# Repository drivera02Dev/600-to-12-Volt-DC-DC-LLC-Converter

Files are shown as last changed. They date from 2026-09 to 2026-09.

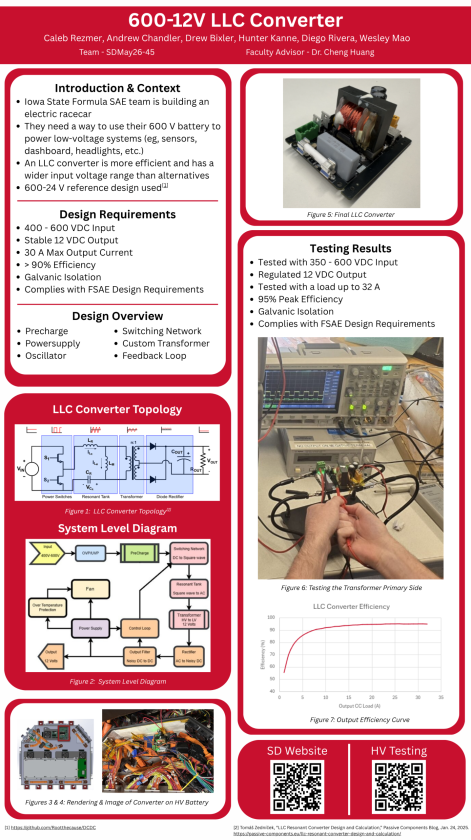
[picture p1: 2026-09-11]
600-12V LLC Converter.png

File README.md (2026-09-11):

# 600V-to-12V-DC-DC-Converter-Senior-Design-Project
## Team
- Caleb Rezmer 
- Drew Bixler 
- Hunter Kanne 
- Diego Rivera 
- Andrew Chandler 
- Wesley Mao

## Overview
This project was proposed by Caleb Rezmer for the FSAE club at Iowa State. This converter will go inside the electric formula car and it will use the 600 Volt battery from the car and step it down to 12 Volts at 30 Amps. It is stepped down to 12 Volts for the internals of the car such as lights, digital displays, fans, and anything else the team would want to add to the car that requires low voltage.

## Role
My role in the project was to make sure the power supply had the proper components it needs to function properly. I had to build and edit the schematic from the reference design we had. I had to verify that at the proper test points it was able to take that high voltage and keep the voltage at a steady 12 volts.

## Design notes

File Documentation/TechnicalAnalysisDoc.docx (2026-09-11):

# EE/CprE/SE 491 Technical Analysis Document Group number: sdmay26-45 Project title: 600-12 Volt Converter Client &/Advisor: Formula SAE

# Precharge/Discharge Circuit (Hunter):

The primary function of the Precharge & Discharge circuit is to charge the capacitor prior to supplying 600VDC current to the DC link capacitor and discharging the 600VDC of the DC link capacitor once the circuit is turned off, respectively. The Precharge circuit uses a constant current to reduce the amount of power going through the resistor and therefore making the resistor much smaller physically.

Going through the entire process of the circuit, we first need a 12VDC supply denoted by V3 to supply the comparators and NMOS’. From there we must look at the “Constant Current Precharge”, V3 is used as a reference in the U10A while the current going through Q4 & R6 determines the comparing voltage. As the comparing voltage drops or rises, U10A increases or decreases its voltage output respectively, by throttling the voltage output from U10A, the gate of Q4 allows more or less current to R6 and thus creates a constant current to the DC link capacitor. It’s worth mentioning the purpose of R51, R49, & D13 is to make the circuit act ideally; R51 is there to increase the stability of the U10A, R49 is to allow current drive to the gate of Q4, and lastly D13 is to prevent a false positive of Q4 during startup that could cause the circuit to turn on without input.

The “Precharge Close” has the function of shorting the DC-link capacitor to the 600VDC source when the capacitor is close enough to 600VDC so as to not cause a large inrush of current. Once more, starting from the V3 source, the 12VDC is used as a reference in conjunction with R47 & R50. However, the 12VDC also flows through R53 to control the input of the U10B. As the DC-link capacitor charges the voltage above D12 & R52 goes towards 0VDC, - once the voltage above D12 & R52 gets below 11.3VDC the V3 source connects to ground through Q4 and activates R52 & R53 as a voltage divider and causes the output of U10B to go high. Once U10B goes high, it activates Q3 and shorts the DC-link capacitor and permanently keeps U10B high. Once again, R7 & R8 are used for stability and serve the same purpose of R51 & R49, but C38 is used to prevent false positives in the event of keeping Q3 closed.

Lastly, the passive discharge is comprised of R47 & R2 by shorting the DC-link capacitor and slowly discharging it in the event neither Q3 nor Q4 are conducting. Due to the size of R47 & R2 the DC-link capacitor discharges slowly, but this is done to reduce the amount of current going through the resistors therefore making them smaller.

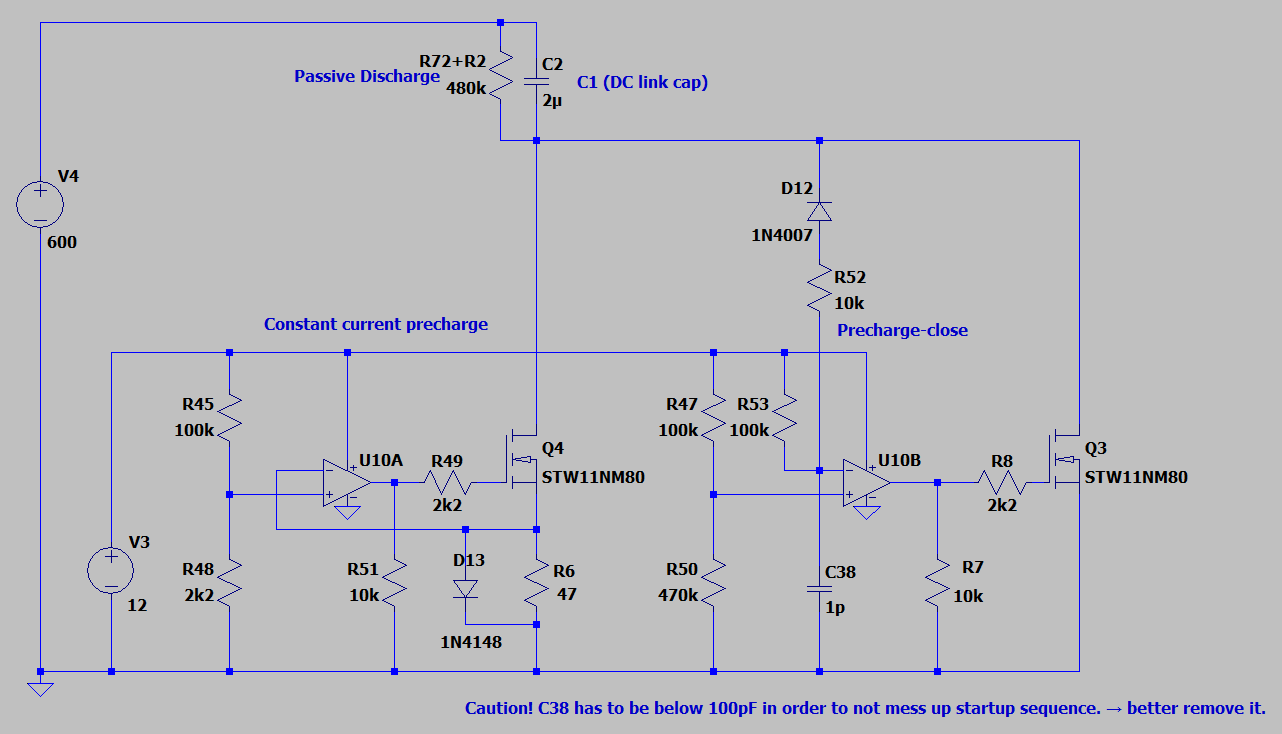
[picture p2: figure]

Parts:

- U10A & U10B: TLV2372DR (https://www.digikey.com/en/products/detail/texas-instruments/TLV2372IDR/381216)
  - 2mV input offset voltage
  - 100mA output
  - +- 16V supply
- R45, R47, & R53: RC0402FR-07100KL (https://www.digikey.com/en/products/detail/yageo/RC0402FR-07100KL/726526)
- R48: RMCF0402FT2k20 (https://www.digikey.com/en/products/detail/stackpole-electronics-inc/RMCF0402FT2K20/2417439)
- R7, R51 & R52: RC0402FR-0710KL (https://www.digikey.com/en/products/detail/yageo/RC0402FR-0710KL/726523)
- R50: RMCF0402FT470K (https://www.digikey.com/en/products/detail/stackpole-electronics-inc/RMCF0402FT470K/1714746)
- R6: RC2010JK-0747RL (https://www.digikey.com/en/products/detail/yageo/RC2010JK-0747RL/5921740)
- D12: 1N4007FL (https://www.digikey.com/en/products/detail/smc-diode-solutions/1N4007FL/11657817)
- D13: MMBD4148 (https://www.digikey.com/en/products/detail/smc-diode-solutions/MMBD4148/6022581)
- Q3 & Q4: IPD80R2k7C3AATMA1 (https://www.digikey.com/en/products/detail/infineon-technologies/IPD80R2K7C3AATMA1/5960264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)
  - 90mJ pulse dissipation
  - 800VDC blocking
  - 42W continuous power
- C38: 04023J1R0BBSTR (https://www.digikey.com/en/products/detail/kyocera-avx/04023J1R0BBSTR/1448935)
- R72 + R2: RCL0612475KFKEA (https://www.digikey.com/en/products/detail/vishay-dale/RCL0612475KFKEA/2579027)

# Primary Stage (Chandler):

The primary stage uses two MOSFETs (IMBG65R050M2HXTMA1) to turn the DC 600V input into an AC signal that can then be used to be stepped down and rectified to 12VDC. The MOSFETs are driven by the UCC25600DR to open and close the MOSFETs and are boosted by the UCC21520DWR gate driver which supports the higher current which is needed to drive the MOSFETs.

Programable dead time is needed to optimize the efficiency of the converter. Using a higher resistance value connected to the DT pin on the UCC25600DR to shorten the dead time. The UCC25600DR also has a programable frequency which is needed to match the frequency of the resonate tank and transformer.

Going through the Circuit, U3 creates the clock signal using a 12v dc input; the dead time is set with the 10k resistor to minimize switching loss. The RT pin is connected to the two series connected resistors and the output of the optocoupler that is on the secondary side of the converted which sets the minimum and maximum switching frequencies. The SS pin is tied to ground with a resistor to set the soft start timing.

GD1 and GD2 are connected to INA high side and INB low side of the U1 gate driver and grounding GND, disable and other unused pins on U1. VCCI, VDDA, and VDDB are connected to the same 12V input as U3 to supply power to both the primary and secondary side of the gate driver. OUTA and OUTB connect to the gates of M1 and M2. The MOSFETS M1 and M2 are connected in series and will alternate when they switch on and off based on the input clock signal. The node that connects M1 and M2 is defined as HB_out which is sent to the primary side of the transformer.

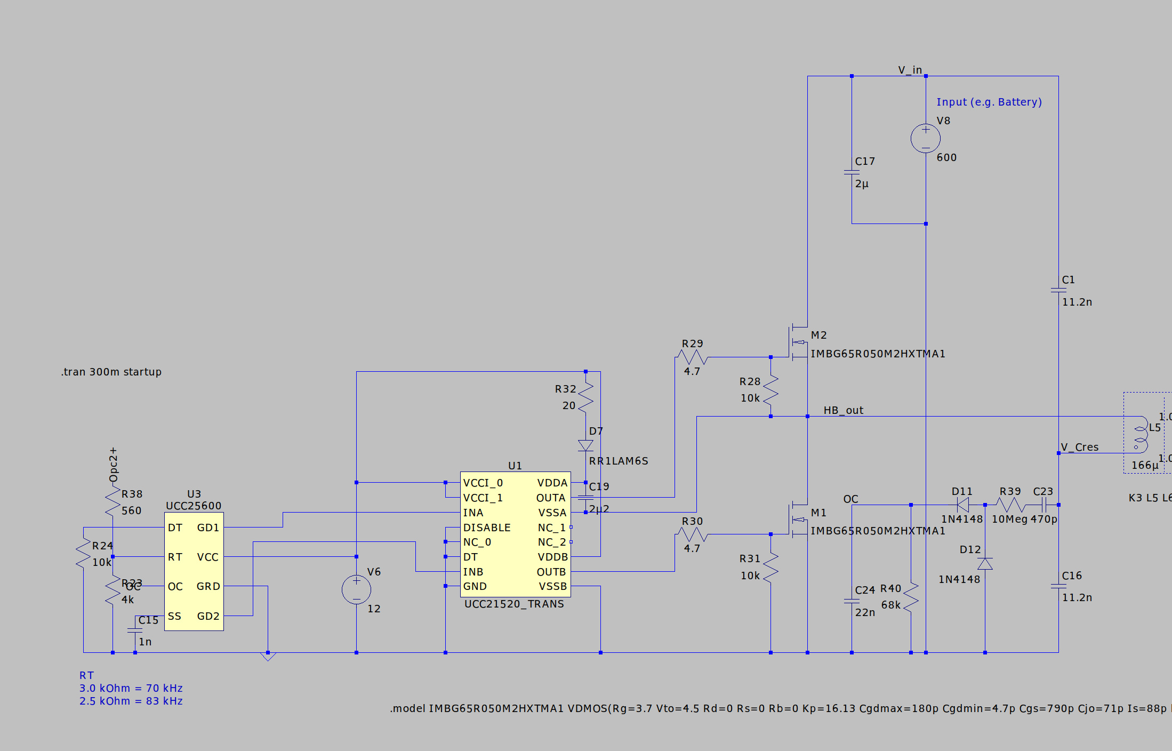
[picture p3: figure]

Components used:

- UCC21520DWR – Gate Driver
  - 33ns propagation delay
  - 8kVpk isolation
- IMBG65R050M2HXTMA1 – MOSFET
  - Very low switching losses
  - Vgs of 4.5V
- UCC25600DR
  - Programable dead time
  - Programable minimum switching frequency
  - 50/50 duty cycle
  - Over current protection

# Secondary Side (Caleb):

The secondary side is defined as the circuit that connects the transformer output, the secondary winding, to the load. The secondary side’s primary function is to rectify the output, 12-volt AC signal, into a stable, smooth 12-volt DC signal. Additionally, the secondary side contains a voltage-controlled feedback circuit to provide galvanically isolated, proportional feedback to the control circuit. To debrief further we will cover each circuit below in more detail:

### Rectifier:

The first circuit on the secondary side is the center-tapped full wave synchronous rectifier. The purpose of this circuit is once again to convert 12-volt AC to a rough 12 volt DC signal. A standard center tapped full wave rectifier is shown below, where the center-tap serves as the output to the load (high-side) and the ends of the transformer are tied to ground via diodes (termed low side). These diodes serve to rectify the AC signal. However, the main issue with using diodes or passive rectification in our application is that we have a relatively low-voltage, large current output, so the voltage drops, and power dissipation of the diodes becomes a significant problem and the bottleneck of the DC-DC converter.

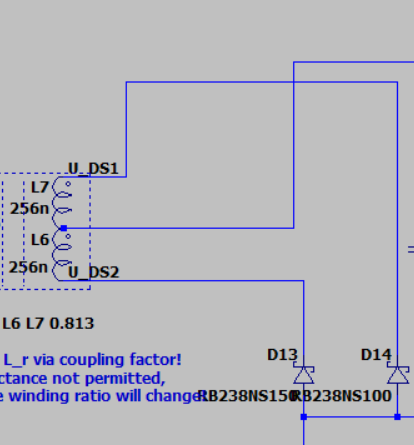
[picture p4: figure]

Figure: Center-Tapped Full Wave Passive Rectifier

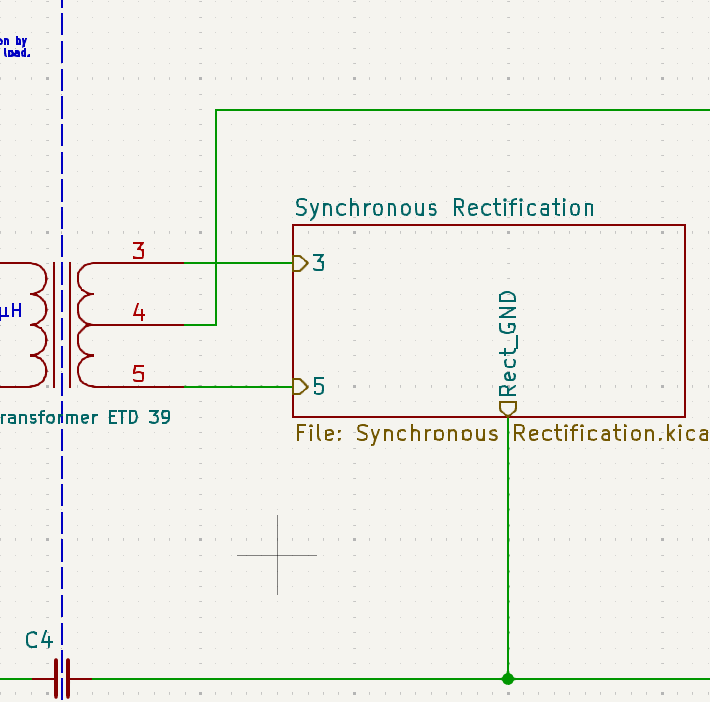
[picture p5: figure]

Figure: Center-tapped Active Rectifier Implementation

The synchronous rectifier solves the conduction loss issue by using MOSFETs to conduct current, which will present a lower voltage drop due to their low RDS-on characteristic. A controller then drives the MOSFETs to synchronize its switching cycle with the AC signal. It does this through a voltage sense pin CS which measures the drain voltage of the MOSFET in reference to ground (the source). When a voltage of less than -.75 mv is sensed at the drain, this means that the body diode of the MOSFET is conducting (forward bias mode) and therefore, the MOSFET is switched on to provide a less resistive path and reduce conduction losses. When a voltage of nearly 0 v is sensed at the drain, this means that the diode is now reverse biased because the current is travelling in the opposite direction through the MOSFETs channel; therefore, the MOSFET is switched off to mock the reverse-bias behavior of a rectifier diode. Essentially, the MOSFET mocks the function of diode with the added benefit of lower conduction loss -an ingenious design.

Components:

- SR Controller: NCP4305DMTTWG (NCP4305 Datasheet (https://www.onsemi.com/pdf/datasheet/ncp4305-d.pdf))
- MOSFET: BSC027N06LS5ATMA1 (Datasheet BSC027N06LS5 (https://www.infineon.com/assets/row/public/documents/24/49/infineon-bsc027n06ls5-datasheet-en.pdf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))
  - RDS-on: 2.7 ohms
  - Power Limit
  - ID: 134 Amps
  - VDS: 60 volts
  - Qc: 24 nc

134 Amps! Note that numbers can be deceiving. Looking closer:

Without proper cooling (copper pour and heatsink), max ID is only 23 Amps. However, with a heatsink, its max is closer to 134 amps at 25 C or 84 amps at 100 C.

- C31 decoupling capacitor specified from datasheet
- R13 and C6 serve to properly trigger the CS pin (validated through testing)
- R42 sets minimum of-time period
- R38 sets the minimum on-time period

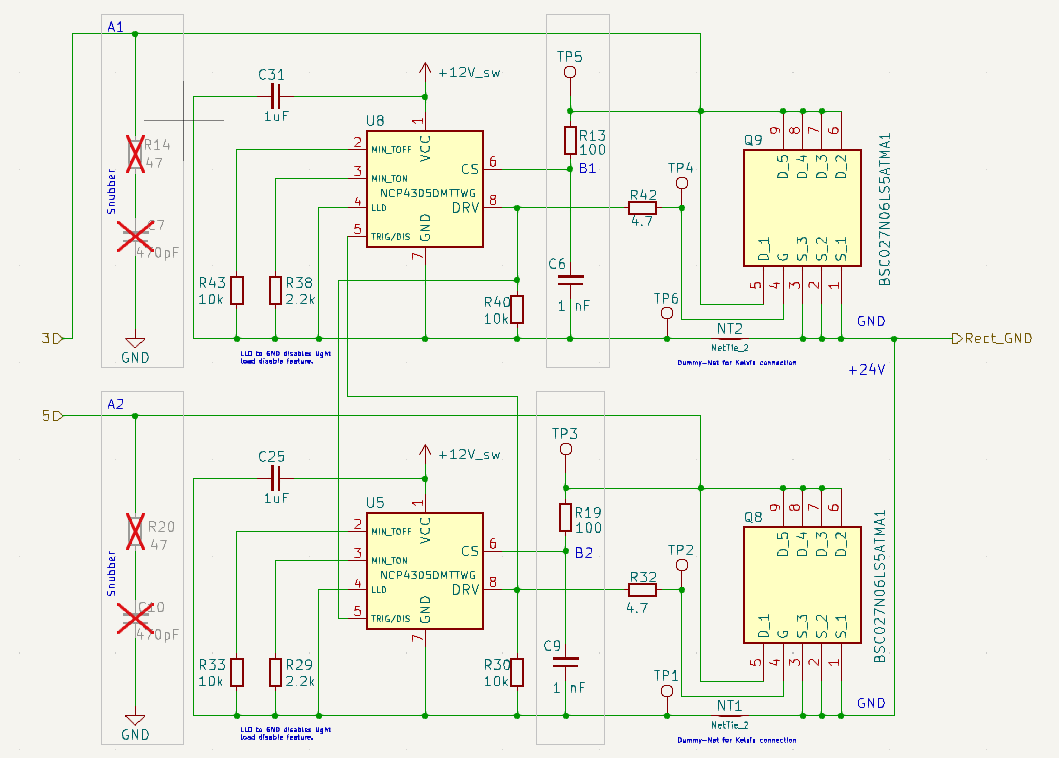
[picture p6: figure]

Figure: Synchronous Rectifier

Calculated MOSFET losses:

- Conduction Losses:

P_(Cond) =I_D ^2 ×R_(ds-on) =4.32 W

### Output Filter:

Sequentially, the next circuit on the secondary side is the Pi filter which serves to smooth out the rectified DC output. The Pi filter is essentially two low pass filters in series.

Inductor:

Current Inductor: 7443091100 Würth Elektronik | Inductors, Coils, Chokes | DigiKey (https://www.digikey.com/en/products/detail/w%C3%BCrth-elektronik/7443091100/10468265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)

New Inductor:

7443091080 Wurth Elektronik | Mouser (https://www.mouser.com/ProductDetail/Wurth-Elektronik/7443091080?qs=d0WKAl%252BL4Kbr2mCzOvoWHA%3D%3D)

Capacitors:

Stage 1:

GRM32ER71J106MA12L Murata Electronics | Capacitors | DigiKey (https://www.digikey.com/en/products/detail/murata-electronics/GRM32ER71J106MA12L/4905643)

New Cap: (5x)

MSAST32MAB5476MPNDT1 TAIYO YUDEN | Mouser (https://www.mouser.com/ProductDetail/TAIYO-YUDEN/MSAST32MAB5476MPNDT1?qs=tlsG%2FOw5FFjVcfO8xtWwSA%3D%3D)

Stage 2:

UHW1V222MHD Nichicon | Capacitors | DigiKey (https://www.digikey.com/en/products/detail/nichicon/UHW1V222MHD/3664337)

# Transformer (Hunter):

# Oscillator and Control Loop (Bixler):

# Power Supply (Diego):

The power supply starts with taking in the stepped down rectified voltage from the transformer. This voltage then gets stepped down via U3, a high efficiency step down converter to 3.7 Volts to charge the super capacitor C_start1. This is achieved by adjusting the voltage from the feedback pin via a voltage divider. U3 is an MP4541_SOP8-EP, and we are using its common configuration provided by the datasheet.

FB Voltage: 1.0 V

V_(out) = 1.0 ⋅(1+27000/10000)=3.7 V

The capacitors C15 and C53 that are in parallel stabilize the input and provide instantaneous current during switching. C17 achieves this as well, however it is connected to the VCC pin on the converter. R25 sets the switching frequency U3 uses via the FREQ pin.

The pulses that U3 produces are then smoothed out by the L3 inductor to make it a continuous DC current. The way this is achieved is when the switch turns off the inductor keeps the current flowing through the diode D7 and resistor R22 into the capacitors C12 and C16 where C16 is connected to the feedback pin on the converter and C12 is connected parallel to the diode D7 and resistor R22. The configuration of the MOSFET Q7 as well as a reversed biased diode D8 is used for reverse current protection and enable gating. When Q7 is off, the inductor releases a kicked-up voltage then is rectified by D9. When the DC is low, current can’t flow back into the converter or input line.

U4 is a TLV61048DBVR which is a boost converter. U4 takes the voltage from the super capacitor C_start1 and boosts it to 12 Volts.

C64 C8 Stabilize voltage and provide instant current during switching.
U2 is a low dropout voltage regulator, and it takes the boosted 12V and converts it to a fixed 9V. C17 C18 provides smoother 12V. The 9V is used to power the fans.

- Can we get rid of the whole step-down converter process since we are not inputting 24 volts and just taking 12 volts directly?
- No, we can’t get rid of the stepping down of the initial voltage since we need it to charge the super capacitor
- All we would need is smoothing from the transformer current
- We still need U2 since the fan circuit uses 9Volts
- Yes, if the fans used 12 Volts instead of 9 Volts we wouldn’t need U2 at all

# Overtemperature Protection (Wesley):

The Overtemperature Protection system shuts down the device when the temperature surpasses the safe operating limit to prevent overheating. The Overtemperature Protection and Fan control are comprised of 2 op-amps. The Overtemperature control op-amp Vin+ is connected to a D10 diode that is connected to the op-amp output for latching. The Vin- is connected to a TH2, which uses the diode to measure the maximum temperature based on the parallel combination of the R36 = 4.7K resistor and parallel resistor. The TH2 impedance changes based on the combined parallel resistance and is converted to a temperature value measured in Celsius. TH2 is connected to the 2 parallel resistors. Right now, for R35 (330K) in parallel to the R36, the TH2 has a resistance of 1404 ohms, which is a temperature of 113.5 Celsius, which is measured as 106.9 Celsius due to noise on the op-amp signals.

The fan control circuit regulates the fan speed by adjusting the current or voltage following into it. When the fan op-amp is on, the fan receives 5.9466 V which converts to 4784 Ohms which converts to 77 degrees Celsius. When the fan op-amp is off, the fan receives 6.0533 V which converts to 4617 Ohms which converts to 68 degrees Celsius.

Components used:

- R36, R35, R34
- TH2, C28, R11, C48
- LM2904BIDDFR (U6A)
- D10
- LM2904BIDDFR (U6B)
- C19, R16
- R75, R31, R15
- R18

# Appendix:

SPICE Simulation Settings:

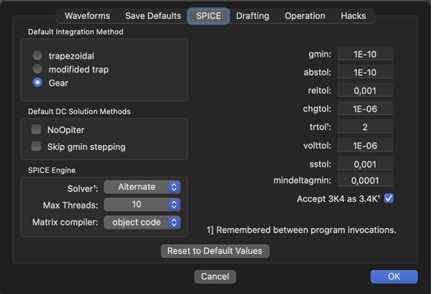
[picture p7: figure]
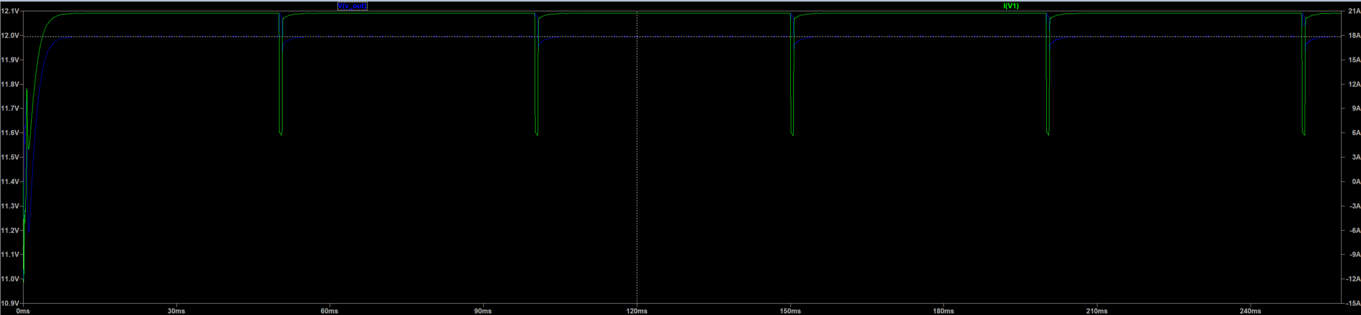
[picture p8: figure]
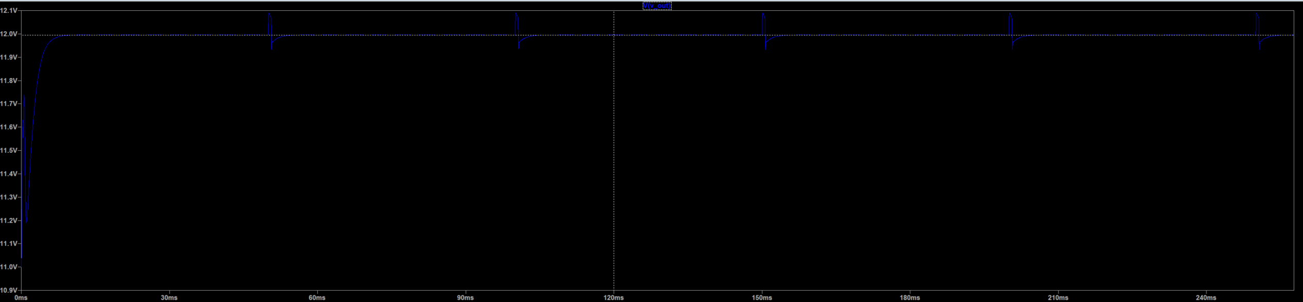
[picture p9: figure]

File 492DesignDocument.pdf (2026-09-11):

# 600-12 Volt DC-DC Converter

DESIGN DOCUMENT

## sdmay26-45

## Formula SAE Club

## Dr. Cheng Huang

## Caleb Rezmer – Team Lead

## Andrew Chandler – Primary-Side Specialist

## Diego Rivera – Power Supply Specialist

## Hunter Kanne – Transformer Specialist

## Drew Bixler – Controls Specialist

## Wesley Mao – Overtemperature Protection

## sdmay26-45@iastate.edu

## https://sdmay26-45.sd.ece.iastate.edu

## Revised: 12/7/2025

# Executive Summary

The Formula SAE team is currently designing an electric racecar, and due to an increase in components, their low-voltage systems (including cooling systems, controls, etc.) demand a substantial increase in power. However, since they have a 600-Volt, 6.8 kWh tractive system battery used to drive the car's powertrain, they are looking to tap into this surplus of available power using a DC-DC converter. The requirements for the DC-DC converter are that it should be able to convert 600 volts – 12 volts relatively efficiently, with the ability to continuously draw 30 amps of current, or in other words, supply 360 watts of power. Since no specific efficiency requirement was listed (due to their power surplus), we set our goal at 90% efficiency to start.

With limited knowledge of the design space, we began researching several DC-DC converter topologies and concluded that the best option was a Half-Bridge LLC Resonant Converter, a state-of-the-art topology that offered substantial design complexity and extensive documentation. With a chosen topology agreed upon, we then searched for resources to support our design. We found an open-source GitHub repository from an FSAE team in Germany that had been developing a 600-24-volt half-bridge LLC topology for several years. However, it was limited to an output current of 20 amps due to the large power dissipation of its rectifier stage. After reading through the team's documentation as well as collaborating with the original design team, we were able to modify the design to fit our design requirements.

The first issue we addressed was to step down to 12 volts rather than 24 volts. We discussed many possibly ways of doing this, but the best way was to simply change the winding ratio from a 28:2 to 28:1 while maintaining similar leakage inductance (forms the resonant inductor). Since we did not have the materials on hand yet to confirm that we could physically achieve this, we asked the previous team to test this theory. They confirmed they could confidently make this change in the winding ratio without altering the leakage inductance.

The next issue we addressed was to increase the output current capacity to meet our requirement of continuously drawing 30 amps, providing 360 watts to the low-voltage systems. Initially, we aimed to replace the synchronous rectification stage with a passive rectification stage; however, we were unable to find diodes that could handle the required current. We were also heavily urged by the previous team to pursue a synchronous rectifier. This was also an issue that the previous design team faced, which is why they designed a synchronous rectifier using MOSFETs instead. Through discussing with the previous design team and reading the MOSFET datasheets, we realized that we could increase our current output from 22 amps to around 80 amps by simply adding heatsinks. We then adjusted our output filtering as well to compensate for the increase in ripple current.

The overall design of the system has been validated through a SPICE simulation containing the switching network, resonant tank, transformer, output filter, passive rectifier (substitute), and control loop. A separate SPICE model contains validation of the precharge circuit. The SPICE simulation results we have obtained give us confidence that our design properly meets the requirements of providing a regulated 12-volt output with a maximum continuous output current of 30 amps at 97.7% efficiency. The converter also responded extremely well to transient response testing with a voltage “droop” of only 18 mV. However, without a proper synchronous rectifier model, some uncertainty remains.

In addition to funding from the department, we were able to secure a sponsorship with Milwaukee Tool through the FSAE club, devising a roughly 50/50 cost split between the department and client. We used JLC PCB to fabricate and assemble many of the SMD components on our boards but did a majority of the soldering ourselves. Since we needed flexibility in tuning the leakage and primary inductances, we designed and fabricated our transformer ourselves.

During our testing process, we first tested the DC supply on the board independently. Furthermore, we tuned the transformer independently and tested it up to 1.8 kV of isolation. After these preliminary tests, we then tested the entire system using a 600-volt power supply, high-voltage differential probes for measurement, and a DC electronic load at the output. After confirming that the converter properly regulated 12 volts at the output, we load-tested the converter at 32 A of output current. We also tuned the switching frequency to 111 kHz to achieve an input voltage range of roughly 350-600 volts, covering the entire SOC range of the high-voltage battery. Finally, we derived the converter’s efficiency curve from our load test data, achieving around 95% efficiency at the car’s normal operating load.

Finally, we implemented the DC-DC converter into the Formula SAE’s electric car. Currently, there is an issue from the clients end that is causing the input voltage to drop to 330 volts. However, despite this, our converter was still able to power the car’s low voltage load. Overall, we exceeded the design requirements and delivered a powerful product to the client.

# Learning Summary

## Development Standards & Practices Used

- IEEE Code of Conduct
- FSAE Design Standards

## Summary of Requirements

- Input voltage of 400-600 volts
- 12-volt stable output
- Output current of at least 30 amps
- Efficiency must be greater than 90%
ο Efficiency is defined by the power at the output divided by the power at the input
- Per Formula SAE standards, the converter requires galvanic isolation
- Voltage separation spacing of 4 millimeters

## Applicable Courses from Iowa State University Curriculum

- EE 456
- EE 303
- EE 201
- EE 230
- EE 475
- EE 476
- EE 332
- EE 330
- EE 232

## New Skills/Knowledge acquired that was not taught in courses

- LLC Converter Design
- Creating a smaller system designed to fit into a larger system
- Physical creation of a transformer
- Physical creation of a large electric system

## Table of Contents

1.1. | Problem Statement | 4
1.2. | Intended Users | 4
2.1. | Requirements & Constraints | 5
2.2. | Engineering Standards | 6
3.1. | Project Management/Tracking Procedures | 6
Task Decomposition | 7
3.2. | Project Proposed Milestones, Metrics, and Evaluation Criteria | 7
3.3. | Project Timeline/Schedule | 8
3.4. | Risks and Risk Management/Mitigation | 10
3.5. | Personnel Effort Requirements | 11
3.6. | Other Resource Requirements | 13
4.1. | Design Context | 13
4.2. | Design Exploration | 16
4.3. | Final Design | 19
4.4. | Technology Considerations | 38

4.5. | Assembly | 39
5.1. | Basic Passive and Active Load Tests | 43
5.2. | Transient Response | 45
5.3. | Power Dissipation/Losses | 48
5.4. | Conclusions regarding full-system simulation | 53
5.5. | Precharge Simulation | 53
6.1. | Unit Testing | 54
6.2. | Interface Testing | 59
6.3. | Integration Testing | 60
6.4. | System Testing | 60
6.5. | Regression Testing | 69
6.6. | Acceptance Testing | 69
6.7. | Security Testing (if applicable) | 69
6.8. | User Testing | 69
6.9. | Testing Results | 69
7.1. | Design Analysis | 74

8.1. | Areas of Professional Responsibility/Codes of Ethics | 75
8.2. | Four Principles | 77
8.3. | Virtues | 79
9. Conclusions | 82
9.1. | Summary of Progress | 82
9.2. | Value Provided | 82
9.3. | Next Steps | 82
10. References | 83
11. Appendices | 83
11.1. | Appendix 1 – Schematics and Layout | 83
11.2. | Appendix 2 – Operation Manual | 88
11.3. | Appendix 3 – Alternative/initial version of design | 96
11.4. | Appendix 4 – Other considerations | 96
11.5. | Appendix 5 – Code | 96
11.6. | Appendix 6 – Team Contract | 96
Skill Sets Covered by the Team | 97
Project Management Style Adopted by the team | 97
Individual Project Management Roles | 97

## Table of Figures

Figure 1: Gantt Chart for Timeline | 14
Figure 2: Tasks and Annotations Close Up | 15
Figure 3: High-Level Project Timeline | 16
Figure 4: Pre-charge Circuit | 28
Figure 5: Block Diagram of Control Loop | 28
Figure 6: Control Loop | 29
Figure 7: Block Diagram of Primary Side | 30
Figure 8: Resonate curve in frequency domain | 31
Figure 9: Primary Side | 32
Figure 10: Block Diagram of Secondary Side | 33
Figure 11: Center-Tapped Full Wave Passive Rectifier | 33

Figure 36: Results Using 240 Watt Active Load Step (Voltage Source with 48 mohm series

Figure 37: Results Using 240 Watt Active Load Step (Voltage Source with 48 mohm series

Figure 49: Conduction Losses Across M2, Pull-Up Half Bridge N-Channel MOSFET (679 mW)...... 56

Figure 50: Conduction Losses Across M1, Pull-Down Half Bridge N-Channel MOSFET (88 mW)... 57

Figure 75: Voltage at Pins 3 and 5 of the Transformer | 73
Figure 76: LLC Converter Efficiency Curve | 75
Figure77: Implementation Schematic | 76
Figure 78: Circuit Block Diagram | 88
Figure 79: Precharge | 88
Figure 80: Oscillator | 89
Figure 81: Overtemperature protection and Fan control | 89
Figure 82: Primary and Secondary Side | 90
Figure 83: Active Rectification | 90
Figure 84: Startup Power Supply | 91
Figure 85: PCB Layout | 92
Figure 86: Front of PCB | 92
Figure 87: Back of PCB | 93
Figure:88 Rev.3 of Transformer | 94
Figure 89: PCB Assembly of THT Components | 98
Figure:90 PCB Assembly of SMD Components | 98
Figure 91: Unsatisfactory High Transient Square Wave Later Fixed | 99
Figure 92: Deadtime Peak Measurement | 99
Figure 93: Half-bridge Output Square Wave | 100
Figure 94: Gantt Chart | 102

## 1. Introduction

1.1. Problem Statement

The problem our team aimed to solve was to design a 600-12-volt DC-DC converter for Iowa State’s Formula SAE team. This converter will be used in the Formula car to power the car's sensors, fans, pumps, and other important low-voltage electronics using a 600V tractive system battery. Without the DC-DC converter, the FSAE team would have to rely solely on a second low-voltage battery in the car, which would lack the capacity necessary to meet their needs.

DC-DC converters are currently used in cars around the world. Our team had found an open-source converter used for another FSAE team car that referenced when we created our own design; however, our design required a lower output voltage than the one we found (12V instead of 24V), and therefore, we created a new transformer for our converter to step down to 12V and modified other portions of the converter to accommodate the new transformer.

1.2. Intended Users

There are three users of our 600V to 12V DC-DC converter:

- The driver:
ο The car driver, David, is only interested in setting fast lap times and needs the car to be reliable and to ‘just work’ so he can focus on winning races. The car gauges always need to be powered, which requires 12v dc to work. The converter is necessary for the car's gauges to be powered.
- The team members of the Formula SAE club
ο The team members of the FSAE club must work together to maintain and repair components on the race car, and require a converter that is relatively small, lightweight, durable, reliable, and most easy to repair. The design of the converter should take into account these needs. Additionally, the FSAE team members benefit from our project because they will be keeping the converter for use in their race car after we finish creating and testing it.
- Car inspectors.
ο The car inspector, Greg, wants all racecars and their components to adhere to Formula SAE rules and regulations, especially regarding safety, and demands that the DC-DC converter be safe and not short-circuit or exceed EMI limits, potentially causing an accident to the driver or other drivers on the track. Greg needs to make sure that all components of the car (including the converter) are safe and reliable, so our solution should take this into account.

Our DC-DC converter meets the needs of all these groups of people who will use, work on, or inspect it, and ensures they meet their requirements for a reliable, safe, and easy-to-maintain DC-DC converter.

## 2. Requirements, Constraints, and Standards

2.1. Requirements & Constraints

There are multiple standards that we followed to ensure a successful outcome for our project. In its most basic form, our design must convert 600 volts to 12 volts; however, it needs to do this with at least 90% efficiency. The system must also supply at least 30 Amps of current.

The system must also have detailed documentation and instructions to facilitate troubleshooting any future issues. Additionally, it should provide a way to incorporate it into the client’s workflow, allowing for potential future revisions.

Finally, the specification requirements are that the system must have each of its components fully operational. If one part of the system is faulty, the entire system will not function; therefore, we need a properly specified power supply, including primary, secondary, and transformer components, as well as an oscillator with proper calibration and no overheating.

We also had constraints while working on this project, such as needing to have a minimum of 90% efficiency with our converter as stated earlier. We would also had to comply with FSAE design competition rules, such as minimum spacing of 14 mils between high voltage and low voltage traces. We would also need to comply with safety, especially when dealing with high voltage and current. This is why the system must be galvanically isolated.

Although not specified, we had to comply with the client’s size requirements. The product must be clean and able to fit where it is needed to, other than that there are no other aesthetic requirements. We worked on a rigorous timeline, as the circuit must function properly by May for the competition, which placed a heavy responsibility on the entire team.

Economically, we were limited to a budget of $1200 in total. Finally, it was difficult to test our product since we had to test it with a 600-volt power supply, which is not something easily obtainable.

2.2. Engineering Standards

Engineering standards are exactly as they sound: standards. Engineering standards hold certain levels of competency for new solutions. Engineering standards can range from reliability to safety, and as such, when building a relatively high voltage converter, standards will apply – safety more so than reliability. When applying standards to the 600-volt converter, both automotive standards and the standards specified by the FSAE design competition must be followed.

IEC 60664 is likely to apply to the 600-volt converter, as the standard outlines the insulation requirements between high-voltage systems and low-voltage systems, which are relevant to the converter. Likewise, IEEE 1100 outlines standards for grounding and voltage isolation. The purpose of the standard is to reduce voltage disturbances between systems on the same board, therefore improving power and grounding quality.

When it comes to safety, the IEEE 1584 standard is a reputable guideline for handling arc flash situations caused by high voltage. The standard outlines the PPE that should be used to prevent burns and the components that can be used to mitigate the risk of an arc flash. Alternatively, the IEEE 519 aims to reduce the size of conductors by minimizing the total harmonic distortion caused by switching in DC/DC circuits. IEEE 519 outlines recommended voltage and current limits to reduce harmonics in the converter circuit, thereby reducing potential failure points.

All four of these standards directly apply to the quality and safety of building a 600-volt converter. We also plan on abiding by the FSAE standards to make the board usable in competition.

## 3. Project Plan

3.1. Project Management/Tracking Procedures

The team used a waterfall and agile management style due to having certain steps that needed to be completed before another, such as doing the circuit design before creating the PCB layout. However, the team also needed to be agile to address issues as they arose as our team wanted to do testing and revisions throughout the two semesters to ensure our design functions as intended. With these requirements in mind, the use of both project management styles was necessary to have a successful project.

The circuit is broken into five sub-schematics that each team member was responsible for completing. These sub-schematics are as follows: Primary Side, Secondary Side, Oscillator, Power Supply, and Pre-charge. There is also the transformer in which a separate team member was responsible for simulating and designing.

The team tracked the progress with weekly meetings by reviewing each of our respective circuit schematics, research updates, or any other idea or question a team member might have during this weekly meeting. This allowed us to see the progress we have made, as well as kept ourselves accountable for the work that we were responsible for completing. The Teams app was also used for general communication and to share our progress, along with any questions or concerns as they arose, so our team was able to continue making progress.

Task Decomposition

- Research LLC Converter topologies
- Source Components
- Get Ki-CAD installed and working
- Download the Git repository and make sure that everything in KiCAD is properly modeled
- Begin building and editing schematics to fit our requirements, each member has their assigned subcircuit
- Build LTSpice models to validate subcircuit functionality and component choice
- Continue to meet and review designs as a team
- Order Transformer parts
- Tune transformer to required specifications
- Layout PCB and coordinate funding
- Begin building the physical 600-12 V converter

- Create detailed test plan
- Gather proper test equipment (LCR meter, Voltage source, power sink, tractive battery)
- Preliminary tests of individual subcircuits such as the power supply
- Isolation test on the transformer
- Starting by testing with lower voltage, lower wattage and work up to max voltage and load
- Document results
- Iterate until design meets requirements
3.2. Project Milestones, Metrics, and Evaluation Criteria

The first milestone in this project was to ensure that we had a proper understanding of how each of our subcircuits works. With the weekly meetings, we updated the team’s progress by either showing any simulations we had done or explaining how certain sections of each person's subcircuit work. We also had a documentation word file in teams, and were able to keep track of progress there as well.

We made sure that the transformer is properly specified since the requirement is to step down 600 Volts to 12 Volts. The transformer is the main part that will do that. We were able to keep track by simulating the transformer and checking if the output matches 12-volts. We also had to test the actual transformer that we designed by first sending in a low voltage to make sure the part works and do different test phases to make sure that it is tuned correctly. Then we followed the FSAE isolation test which states that it should not break down when testing three times the voltage of the battery maximum of 600-volts. This means our transformer must be able to operate at 1800-volts AC RMS for one minute.

We needed to also make sure that the schematic was simulated properly and how we wanted it. We used specific manufacturer parts in the simulation. We needed to make sure that we simulated it before ordering anything. There could always be last-minute changes depending on part availability.

There are many parts that needed to be ordered for the converter; however, by the time we were ready to order them, we predicted that it would be likely that some of them would be out of stock, therefore, we found proper replacements for any part that would be out of stock to mitigate this issue before it occurred. If we didn’t do this, any missing part would take us back to the simulation stage; the only difference is that we would need to be quick with simulating the second time around, and ordering. We made a spreadsheet with every single part that we needed, and once a part was ordered, we marked it as ordered or edited in the case we needed to replace it.

Once all the parts were ordered, we assembled the product on the PCB we ordered, along with all the other parts that were ordered. Luckily, we decided we must order a minimum of 5 PCB’s so in the case of any error in the circuit or something that doesn’t work properly, we have backup PCBs. Once the assembly was completed, we proceeded to test the converter.

Testing a converter at this high voltage was a big milestone, as we didn’t have access to a single power supply that reaches the required high voltage. We ended up using cascading power supplies to reach the required voltage and ensure that the converter worked properly before giving it to FSAE. The ideal test is to have the actual battery that will go into the car and connect our converter to it to make sure it works properly.

Another major milestone was making sure that the PCBs we ordered are tested properly and pass all the tests we have for them. This is to make sure that all the low voltage systems work properly before putting the transformer on the board and start testing at high voltage levels. At the same time as testing the low voltage systems, we were also testing and tuning the transformer to have the proper inductance values.

3.3. Project Timeline/Schedule

To ensure success, we developed an Excel Gantt chart, as illustrated in Figure 1 below. The Gantt chart is essential to maintaining accountability and steady progress towards our goals. Tasks are color-coded to indicate high, medium, or low risk based on their urgency. Additionally, milestones and goals are established to further emphasize urgency. Each task is also annotated and assigned as shown in the zoomed-in image in Figure 2.

Figure 1: Gantt Chart for Timeline

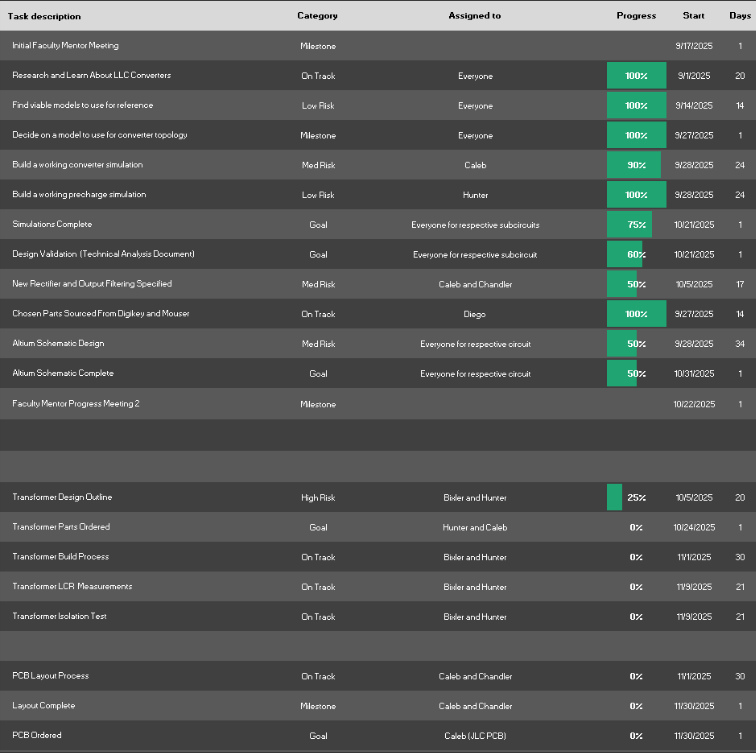
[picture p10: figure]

Figure 2: Tasks and Annotations Close Up

We also created a high-level project timeline that encapsulated the entire project, as shown in Figure 3. We approached this project in phases, from research to implementation, which made our progress feel more tangible. In retrospect, we closely followed this timeline, which led to the successful delivery of our converter. The transformer design took slightly longer than we initially thought, which was the only major deviation from the original timeline.

Figure 3: High-Level Project Timeline

3.4. Risks and Risk Management/Mitigation

We used the variable R to estimate the risk associated to each task required for the creation of our 600-12 V DC to DC converter.

- Converter design
ο | Selecting components with proper parameters (R = 30%)
ο | Creation of the full system with everyone's circuit implemented (R = 65%)
ο | Simulation of the design once completed (R = 5%)
- Creation of physical converter
ο | Order components (R = 15%)
ο | Create PCB (R = 10%)
ο | Order PCB (R = 5%)
ο | Assemble components on PCB (R = 70%)

Overall, we do not believe there is a large risk to this project. If the worst-case scenario had come to pass and our project was not completed on time, the Formula SAE team still could have ordered a less efficient and more expensive part, such as a buck converter, to replace the converter in their race car. Furthermore, there are a limited number of ways in which this task introduces safety risks to our team. Regardless, there are a few tasks that present more risk, both in terms of completing the project on time and maintaining personal safety, than other tasks.

The first task that presented more risk was the simulation of the design once completed. The reason that we believed this task presented more risk was that it was the last opportunity to catch issues with the design before ordering parts. If we made any mistakes in the selecting components task or the schematic creation tasks, and they were not found here, we would not know until we had completely ordered the parts and put together the LLC. To remedy this, we all be constructed our own section of the simulation, and then everyone reviewed each portion of the simulation to ensure that everyone believed each part was correct. By doing this, we would be able to significantly reduce the risk of simulation being incorrect.

The next task that involved more risk was creating the PCB. PCBs are not very expensive, so there isn’t much financial risk involved in this process. On the other hand, custom PCBs can sometimes take a fairly long time to ship. This means that if we had messed up the design, it was possible that it could have sidelined us for an extended period. This would have been very bad, as at the stage of the project where we were ordering a PCB, there isn’t that much else we could have worked on at the same time. To mitigate the risk of time delay at this portion of the project, we split up creating the PCB and ordering the PCB into two distinct tasks. This gave us an opportunity to review the PCB before we ordered it and ensure it matched the design we had. Furthermore, we aimed to order the PCB before winter break, so if we made an error in the creation stage, we would still have plenty of time to rectify it and finish the project on schedule.

The final task that presents an elevated risk is assembling the components on the PCB. There are a number of ways in which this task can prove harmful to the project. The first of which is if we were to solder a part on in the wrong location or fry a component. This would have forced us to delay working on the project until we had time to order and receive a new PCB or component, depending on the severity of the problem. To mitigate this risk, we ordered multiple PCBs and multiple of each required component, so that if we had messed up at this step, it would not have forced us to delay the project. We had calculated the cost of the project already and ensured that it is within the projects budget to order multiple of each part to reduce the risk in this step. The second risk in this portion is the possibility of someone accidentally getting hurt due to the high voltage required for this project. To reduce the risk of injury, we had a meeting after we received the PCB, where every member of the group would review the IEEE safety standards, as well as general best safety practices when soldering and working with high-voltage components. This gave us a chance to ensure that we all understand both the risks associated with our project and how we can work safely to complete it on time.

The only major risk outside of testing that has affected this project so far was the budget issue. We had miscalculated the project's original cost; this issue was resolved when we secured funding from Milwaukee Tool. During testing, there were many risks and potential problems. Since we were dealing with a board that would eventually handle high voltage, we had components such as capacitors right next to each other, and if we weren’t careful, we could have easily created a short circuit and destroyed a chip or another component. We also had a supercapacitor that is dangerous. We had to be careful when handling it and when discharging it. We also tested with high voltage which itself is a risk not only to the components but to ourselves.

3.5. Personnel Effort Requirements
Task | Number of person-hours to perform
Building the schematics | 30
Simulation | 30
Layout of Schematic | 30
Building the 600-12 V converter | 40
Documentation of design | 30
Meetings | 2-3 per week
Table 1: Personnel effort requirements (first semester estimate)

Team Member | Total Hours
Caleb Rezmer | 155
Andrew Chandler | 138
Drew Bixler | 119
Diego Rivera | 103
Wesley Mao | 68
Hunter Kanne | 94
Meetings | 2-3 per week
Table 2: Team member hours
Task | Number of person-hours to perform
Building the schematics | 20
Simulation | 10
Layout of Schematics | 20
Building the 600-12 V converter | 50
Documentation of design | 20
Testing (New section) | 60 (Current phase)
Table 3: Personnel effort requirements (second semester revision)

We spent most of our hours testing the board and designing the transformer. We did not spend as much time as we estimated we would for each section listed above.

3.6. Other Resource Requirements
Software: | Ki-CAD, LTSpice, Microsoft Excel, Microsoft Word, AutoCAD inventor,
Waveforms

Hardware: High Voltage Battery, Cooling Fans, LCR Meter, Multi-meter, Oscilloscope, Waveform generator, Power Supply, Thermal imaging camera, Soldering Iron, PCB oven, & 3D Printer.

Parts & Materials: Capacitors, Inductors, Resistors, HV Fuse, PCB, PLA, Ferrite core, Transformer winding wires, Cooling fans, plastic clamp, Solder, Flux, Comparators, Transistors, FETs/MOSFETs, Optoisolators, & Buck Converters.

## 4. Design

4.1. Design Context

4.1.1 Broader Context

This design is for the FSAE community. Considering a broader context, this product is used in electric vehicles. However, it is not used in all electric vehicles, even though it is a more efficient alternative than the buck converters they currently use ubiquitously. The societal need that this project addresses is to increase the efficiency of our electric vehicles, resulting in reduced power consumption.

We would reduce overall power consumption with this LLC converter. Not just reducing power consumption but replacing the current solution that the FSAE has for the low voltage systems of hot swapping batteries, which means in the long term, having to purchase multiple batteries and constantly charging them instead of having a system that uses the main battery and there would be no need for a stop to replace the low voltage batteries.

The project would reflect the practices of the FSAE, an engineering design competition that focuses on what engineers do: making products as efficient and effective as possible. Especially in a competition setting, where every small optimization would give an advantage.

The environmental impact that this project has is that it has less power waste compared to buck converters and less physical waste, such as batteries. It is a more efficient alternative to both solutions.

The economic impact of the LLC converter is that although it is a large initial purchase, it is a much more efficient and convenient solution than the other two options. The cost would make an overall normal electric vehicle more expensive however for commercial use it provides high efficiency and reduces power dissipation which would save on power costs. It also provides superior performance in steady state and transient conditions.

Area | Description | Examples
Public health, safety, and welfare | The LLC converter positively affects the stakeholders in the project. | The converter increases power efficiency for the ISU FSAE team, allowing them to use less energy on low voltage electronics such as gauges for the car. The converter also positively affects financial stakeholders like Milwaukee tool as a working converter reflects well on their financial contribution.
Global, cultural, and social | The converter adheres to both IEEE and FSAE guidelines and reflects the standards that our converter is evaluated at. | Such guidelines as transformer isolation, EMI, Low voltage and high voltage signal isolation, High voltage labeling, PCB trace widths and lengths, and PCB dimensions.
Environmental | The LLC converter is more power efficient than other converter types. However, the LLC converter utilizes ICs, PCBs, Copper, and other materials in the manufacturing process. | The manufacturing and refinement of these materials is known to have negative impacts on the environment.
Economic | Large upfront cost especially in lower quantities. | May not be as economically viable for some smaller FSAE clubs with less funding; however, for automotive companies the design is more practical.

Table 4: Areas of relevant consideration related to project

4.1.2 Prior Work/Solutions

Several DC-DC converter products exist on the Digi-Key and Mouser markets. These include products made by TDK-lambda, XP Power, Cincon Electronics, Mean Well, OmniOn, Vicor Corporation, and Artesyn. Such products include the PAF600F48-12 DC-DC Converter (12V, 600W), QHL600 DC-DC converter, LTD CFB600-48S12 DC-DC Converter, Q DC-DC Converter, and others. However, none of these meet the specifications of our project: an input voltage of 600 volts, an output voltage of 12 volts, and a current output of 30 amps. We could not find a DC-DC converter that meets our specific requirements from our market research, which is the primary motivation behind this project. However, we found an open-source DC-DC converter design on GitHub that could be modified to meet our design requirements. This is the design that we have based our converter on and have been closely communicating with the previous designers. We based our decision to pursue the DC-DC converter based on the following:

Pros:

- Converts Vin of 400-600 volts of power into 12 VDC highly efficiently
- Cost-effective low-voltage source
- Compact and energy efficient

Cons:

- No reverse polarity protection
- Lower thermal safety for some components
- Time-consuming and costly development

4.1.3 Technical Complexity

An LLC converter is a state-of-the-art converter topology that features numerous subsystems and complex technical concepts, which collectively contribute to its functionality. Each subsystem requires a deep foundation of electrical engineering knowledge to both understand and design, including magnetics design, controls, semiconductors, analog circuits, and electromagnetic interference. There are eight subsystems within the LLC converter: the pre-charge, half-bridge, resonant tank, transformer, rectifier, control loop, power supply, and overtemperature protection, all of which are interdependent.

The pre-charge circuit requires knowledge of op-amps, precision programmable references, MOSFETS, and other fundamentals, which all serve to properly charge up the input node of the circuit and filter out transients. The H-bridge circuit, which contains a half-bridge switching network, converts the DC into an AC square wave. The resonant tank then filters the harmonic content of the square wave to refine it into a sinusoid, enabling more efficient power conversion and reduced switching losses across the MOSFETs. Since the resonant tank circuit also has a gain curve, altering the switching frequency alters the overall gain of the system. An LLC controller chip uses this frequency-dependent gain curve to regulate the output. Proportional feedback from the output is used to adjust the switching frequency, maintaining an output voltage of 12 volts.

Next, the transformer is designed to serve two separate functions simultaneously. Its primary function is to step down the input voltage of 600 volts to 12 volts through coupling. However, the transformer is also gapped and tuned so that its leakage inductance serves as an inductor for the resonant circuit. Tuning the transformer to the required specifications to meet both functions is a feat of considerable complexity. Finally, the secondary side of the transformer contains a synchronous or active rectifier to convert the low-voltage AC back into low-voltage DC. This circuit is much more complex than a simple diode rectifier because it uses MOSFETs that switch synchronously based on a voltage sense to decrease conduction losses; rather than suffering from the .7 volt drop from a diode, the current only has to travel through a few milliohms of RDS on. Finally, an output pi filter is tuned to properly smooth the waveform from ripple.

The complexity of the LLC converter speaks for itself.

An LLC converter is complex on its own; however, we did not make one from scratch. We used an open-source design as a reference for our application of an LLC converter. The main change that we made is that the open-source project steps down 600-Volts to 24-Volts. However, ours stepped down to 12 volts, which comes with many complex ramifications. In addition, we needed to substantially increase our output current from 21 amps to 30 amps.

We needed tune and test different parts of the converter to ensure that everything is suitable for the 12-volt output. Many parts of the open-source system were specifically designed to work with 24-Volts.

4.2. Design Exploration

4.2.1 Design Decisions

The main three decisions that we have had to make regarding our LLC converter was whether we make a transformer from scratch or find and order one that fits our requirements, whether we should use active or passive rectification, and what kind of transformer we want to create. We decided that we are were to create our own transformer and use active rectification, solving our first two design decisions. To solve whether we should use a premade transformer or make our own, we started by searching for what premade transformers exist. The purpose of doing this was to learn how realistic it would be to use a transformer that was premade. We then ran through the pros and cons of making our own or buying one during one of our weekly meetings. In the end, we decided that creating our own transformer would allow us to save money, give us the flexibility to modify and tune it, and be more technically complex. This had a large effect on the project because creating the transformer was a challenging portion of our project. Furthermore, the transformer is what is actually stepping down the voltage in our converter, meaning that it is crucial to the functionality of our converter and how efficient the converter is.

The second design decision that we had to make was whether we should use passive or active rectification. For this particular decision, we decided it was important to get some more feedback on the decision, so we discussed it in a meeting with our faculty mentor. Furthermore, we reached out to other people that have created LLC converters before, and found that while passive rectification would likely work for our circuit, there was some risk involved that the diodes needed for passive rectification would burn out when dealing with the high currents involved in a LLC converter. Because of this, we chose to proceed with the plan of using active rectification in our circuit. This decision increased the complexity of our project but ensured that the converter does not break quickly after being created due to diodes shorting out. Therefore, this decision ultimately allowed the project to be more successful, as using active rectification created a significantly more robust LLC converter.

The third design decision that was necessary for our project was determining what kind of transformer we should use in our circuit. This decision came up after we decided that we would build the transformer ourselves. This decision was difficult, as there are a large number of different transformers that can be used to create an LLC converter, meaning there were a large number of different options that we could go with. In the end, we decided to use a center tapped transformer with an internal resonant inductor. We made this decision by discussing during a group meeting the pros and cons of each of the different options and coming to a group consensus on which option we decided to go with. We chose to use a center tapped transformer with an internal resonant inductor because it is a commonly used transformer design for LLC converters, meaning that there is a lot of information that we can utilize in the design of our own transformer. Furthermore, it allows us to keep the general size and functioning of our transformer like that of the transformer that is used in the LLC converter we are referencing when designing our own LLC converter. This choice allowed the project to work very efficiently and our project technically complex without making it too complex to finish in one school year, thus ensuring the success of our project.

4.2.2 Ideation

When we were deciding what type of transformer that we would create, we started by having each group member do some individual research and come up with a couple different options each. From this stage, we came up with a couple of different choices. The first choice was whether we would use an internal or external resonant inductor. The second choice was whether we would center tap the windings for the inductor or not. What this means is whether we would use a wire coming out of the middle of the windings so that we could have more windings while still getting the exact ratio we need to step our signal down from 600 V to 12 V. The third decision to make was the core shape. Some of the options that we came up with for the core shape included an ETD form factor, and a PQ form factor. All in all, there were three major design decisions with two options each, totaling six total choices, and eight different possible combinations from the options available. During our following weekly meeting we had each member research pros and cons of each option for a couple of minutes. While doing this part, we made sure everyone was researching it individually to try and minimize the possibility of us missing any pros or cons. After this, we discussed as a group to try and come up with what we all though was the best idea to go with for the project. We ended up deciding on using an internal resonant inductor, with a center tapped winding, and a ETD form factor. The reason that we chose the internal resonant inductor was largely because it simplifies the design of the circuit outside of the transformer. This allows us to get the same functionality out of a less complex circuit, at the cost of making the transformer a bit harder to make. There is plenty of information out there regarding creating a transformer with an internal resonant inductor, so we decided that this would be a safe decision to go with. We also decided to use a center tapped winding, as the majority of LLC converters that we could find were used for large voltage drops, like the one we are creating, use center tapped transformers in order to make a transformer that is more typical. This will make it easier to find information regarding how to actually design the transformer and will not come up with any drawbacks in terms of efficiency. Finally, we decided to use an ETD form factor because it makes it easier to use windings with a large cross section. Being able to use windings with a larger cross section will help with the leakage induction and the isolation, meaning that the transformer will be more efficient and will also be better galvanically isolated. Galvanic isolation was a big reason as to why we chose to use an LLC converter, so choose an option that helps support that allows our project to better fit the design parameters of the client.

4.2.3 Decision-Making and Trade-Offs

The process that we used to identify the pros and cons of our ideated options was to have every member do individual research, before collating our research to create a large pros and cons list. From there, we discussed the benefits and drawbacks of each option to try and come up with the solution that made the most sense. While discussing which option to go with, we made sure to prioritize benefits and drawbacks that related to the design parameters we have received from the client, as well as focus on options that better fit some of our focus points in our LLC converter. Some of these focus points include making a converter that is highly efficient, small, lightweight, and has galvanic isolation. While discussing options, we did discuss the benefits and drawbacks that were not related to these focus points, such as the availability of resources to learn about the options, but we made sure to put more weight into the pros and cons that help us deliver these focus points that our client desires.

The reason that we chose the method that we did was twofold. First, we had every group member do individual research so that if any group member missed something, at least one member of the group would likely have seen it in their own research. This let us be more thorough when creating our list of pros and cons. Furthermore, it made it such that every group member was well versed in the different options when it came to discussing the options and deciding which to go with. The reason that we discussed each option as a group was because at the start of the semester, we all agreed that we would discuss major design decisions as a group before choosing one, and we want to stick to this promise that we made. The reason that we decided to make this agreement was because we believe that it allows us to come up with the best solution to fit the needs of our project, due to the fact that the discussion allows group members to each advocate for what they believe is the right solution. This helps to ensure that everybody sees all the good and bad for each option. This also helps to make it such that by the end of debating what option works best, we will be able to come to a complete and well-informed decision on what option works best for our project. It’s worth noting that when we have discussions on design decisions such as this, we typically will listen more to whatever group member is the specialist for the part of the circuit being worked on, but every group member still gets a say on what the final decision is.

4.3. Final Design

4.3.1 Overview

The high-voltage DC/DC LLC converter takes power in the form of voltage and current from the high-voltage car battery as an input. The 600VDC input must then be converted to AC through the use of switches (MOSFETs) and turned into a typical sinusoidal wave via the “resonant tank”. Once the 600VDC input changes into a typical 600VAC wave, it may then go through a transformer that

decreases the voltage by a ratio to 12VAC while increasing the current by the inverse of that voltage ratio. Lastly, the 12VAC wave must be changed back into a DC signal by use of rectification, as seen in the figure below (Figure 3).

Figure: How a Transformer works (https://media.monolithicpower.com/wysiwyg/Articles/A-0028_fig1.png)

4.3.2 Detailed Design and Visual(s)

Figure: Flowchart of Systems

− | The subsystems are split up into the following:
− | Pre-charge/Discharge
ο | OVP/UVP
ο | Pre-charge
− | Oscillator & Control Loop
ο | DC/DC Control
− | Primary stage
ο | FET Half Bridge
ο | Gate-Driver
− | Transformer
− | Secondary Side
ο | Rectifier
ο | 12V Output
− | Power Supply
ο | Buck Converter 12 to 3.7V
ο | Supercap 3.7V
− | Overtemperature Protection
ο | Temperature Surveillance
ο | Fan 3.7/12V

The Pre-charge and discharge circuits help pre-charge and discharge the DC link capacitor which smooths out the voltage from the high voltage battery. The DC/DC control loop regulates how much current is demanded from the high-voltage battery. From there, the primary stage converts the 600VDC to 600VAC through the use of the gate driver, which controls the FET Half Bridge. Next down the line, the Transformer converts 600VAC to 12VAC along with increasing the current. The secondary side converts the 12V AC to 12V DC, resulting in a 12V output. This voltage is too much for the Supercap, so it is stepped down with the Buck Converter from 12 to 3.7V. The supercap is utilized to act as a battery of sorts, so the board can be powered for long periods of time while off. From there, the temperature surveillance system monitors the transformer and the surrounding system and controls a fan.

Precharge/Discharge Circuit:

The primary function of the Pre-charge & Discharge circuit is to charge the capacitor prior to supplying 600VDC current to the DC link capacitor and discharging the 600VDC of the DC link capacitor once the circuit is turned off, respectively. The Pre-charge circuit uses a constant current to reduce the amount of power going through the resistor and therefore makes the resistor much smaller physically.

Going through the entire process of the circuit, we first need a 12VDC supply denoted by V3 to supply the comparators and NMOS’. From there, we must look at the “Constant Current Precharge”, V3 is used as a reference in the U10A, while the current going through Q4 & R6 determines the comparing voltage. As the comparing voltage drops or rises, U10A increases or decreases its voltage output, respectively. By throttling the voltage output from U10A, the gate of Q4 allows current to R6 and thus creates a constant current to the DC link capacitor. It’s worth mentioning that the purpose of R51, R49, & D13 is to make the circuit act ideally; R51 is there to increase the stability of the U10A, R49 is to allow current drive to the gate of Q4, and lastly D13 is to prevent a false positive of Q4 during startup that could cause the circuit to turn on without input.

The “Pre-charge Close” has the function of shorting the DC-link capacitor to the 600VDC source when the capacitor is close enough to 600VDC so as not to cause a large inrush of current. Once more, starting from the V3 source, the 12VDC is used as a reference in conjunction with R47 and R50. However, the 12VDC also flows through R53 to control the input of the U10B. As the DC-link capacitor charges, the voltage above D12 & R52 goes towards 0VDC. Once the voltage above D12 & R52 gets below 11.3VDC, the V3 source connects to ground through Q4 and activates R52 & R53 as a voltage divider and causes the output of U10B to go high. Once U10B goes high, it activates Q3 and shorts the DC-link capacitor and permanently keeps U10B high. Once again, R7 & R8 are used for stability and serve the same purpose as R51 & R49, but C38 is used to prevent false positives in the event of keeping Q3 closed.

Lastly, the passive discharge is comprised of R47 & R2 by shorting the DC-link capacitor and slowly discharging it in the event neither Q3 nor Q4 is conducting. Due to the size of R47 & R2, the DC-link capacitor discharges slowly, but this is done to reduce the amount of current going through the resistors, therefore making them smaller.

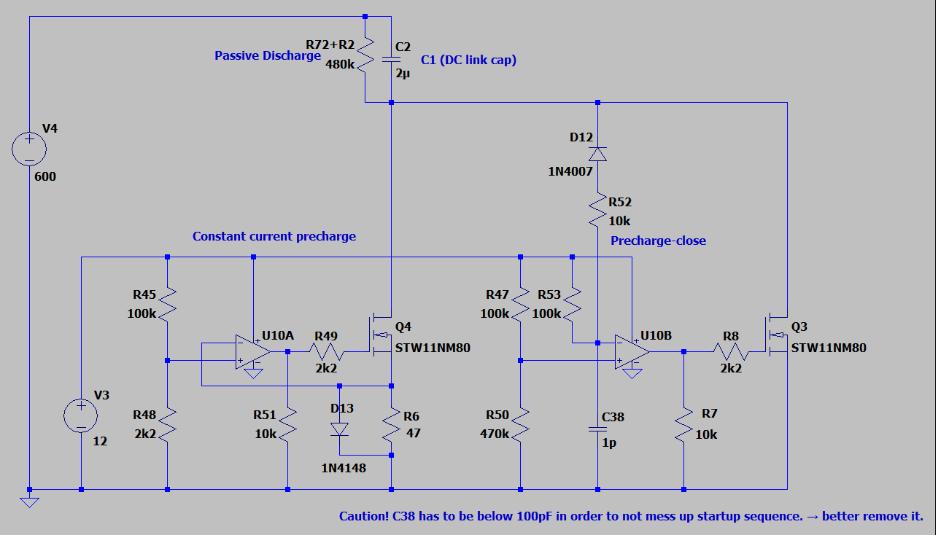
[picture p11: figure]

Figure 4: Pre-charge Circuit

Control Loop:

The purpose of the control loop is to regulate the output of the converter at 12V DC. To do this, it measures the output voltage, and if the output voltage is above 12V, it increases the switching frequency of the switching network which causes the converter’s gain to decrease. It continues to increase the switching frequency until the converter’s output is 12V. If the measured output voltage is 12V or less in the first place, the control loop doesn’t do anything. In effect, this delivers instantaneous voltage regulation holding the output of the converter at the required 12V.

The purpose of the control loop in the LLC converter circuit is to maintain zero voltage switching and keep the output voltage of the circuit constant at the required voltage level. This makes it so that if voltage spikes on the primary side of the circuit, the converter’s output voltage will remain constant. This is incredibly important, as the converter powers several different sensitive electronics that could get destroyed if the converter outputs too high of a voltage for a sustained period.

The main component of the control loop is a TL431 comparator. This component compares voltage to an internal reference voltage. The internal reference voltage of this comparator is 2.5V. The output voltage is sent through a voltage divider with the output connected to the reference pin. The resistors for the voltage divider are set up such that the voltage coming out of the voltage divider is just below 2.5 V. This makes it so that if the voltage at the converter’s output spikes, the voltage going into this reference pin will exceed the comparator’s internal reference voltage. If this happens, a current runs through the comparator, increasing the current at an optocoupler. The optocoupler then gets the control chip (the control chip is covered more intensely in the primary side section of this document) to increase the switching frequency, which in turn decreases the converter’s output voltage.

Figure 5: Block Diagram of Control Loop

This will continue to happen until the reference voltage coming out of the voltage divider is below the comparators' internal reference voltage. There are resistors and capacitors being used between the TL431 comparator and the optocoupler for the purpose of smoothing the signal between them, as well as acting as low-pass filters to ensure that high-frequency noise does not cause the converter to start adjusting the switching frequency, as well as the converter output, unexpectedly and when it is not supposed to.

Components Used:

- TL431 – Comparator
- Internal reference voltage of 2.5 V
- If input voltage exceeds internal reference voltage, a current flow from the output of the comparator
- APCL-217-50AE - Optocoupler
- Used to provide galvanic isolation
- When it receives a current from TL431 comparator, sends a signal to UCC25600DR resonant mode controller to increase the switching frequency
- R17 and R12 – Resistors
- Used in a voltage divider to create the input voltage for the TL431 comparator
- At converter output of 12V, the comparator input voltage should be ~2.48V
- C26, C29, C30, C32 R37, R41, R39 – Resistors and Capacitors
- Used to provide low pass filtering so that high frequency noise does not cause unexpected errors in the LLC converter’s output

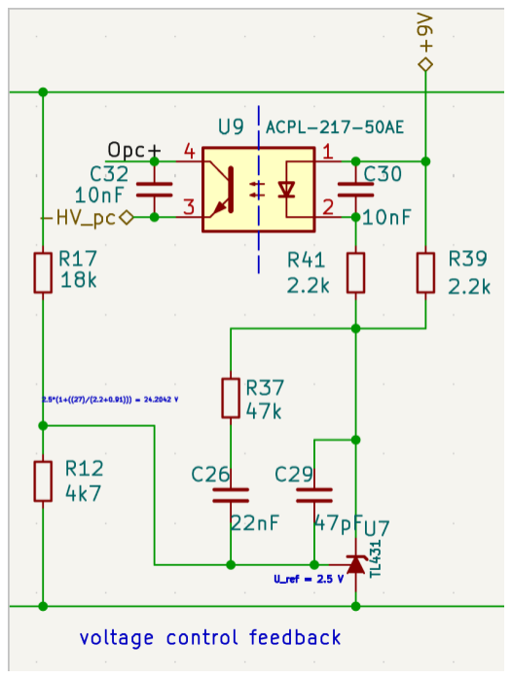
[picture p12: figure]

Figure 6: Control Loop

Primary Side:

At a high level, the primary side consists of a switching network and a rectifier. The switching network is used to turn the input DC voltage into a square wave signal. The rectifier is used to turn the square wave signal into a sinusoidal AC voltage. The purpose of turning the DC input into an AC voltage is to allow the transformer to step the voltage down with a high degree of efficiency. This prevents losses due to things like waste heat that would occur if we tried to directly step down the DC voltage. A block diagram detailing the primary side from a high level is included below.

Figure 7: Block Diagram of Primary Side

The primary side uses two MOSFETs (IMBG65R050M2HXTMA1) to convert the DC 600V input into an AC signal, which can then be stepped down and rectified to 12VDC. The MOSFETs are driven by the UCC25600DR to open and close the MOSFETs and are boosted by the UCC21520DWR gate driver, which supports the higher current required to drive the MOSFETs.

Programmable dead time is necessary to optimize the converter's efficiency. Using a higher resistance value connected to the DT pin on the UCC25600DR to shorten the dead time. The UCC25600DR also has a programmable frequency, which is needed to match the frequency of the resonate tank and transformer. The OC pin is used for overcurrent protection. When the OC pin exceeds 1V, the power stage shuts down, utilizing the sensing circuit, which uses the bottom-resonate capacitor voltage, proportional to the load current. If the load current is too high, the OC protection pin voltage will increase, causing the U3 chip to limit the current and potentially restart the circuit.

Going through the Circuit, U3 creates the clock signal using a 12V DC input; the dead time is set with the 10k resistor to minimize switching loss. The RT pin is connected to the two series-connected resistors and the output of the optocoupler on the secondary side of the converter, which sets the minimum and maximum switching frequencies. The SS pin is tied to ground through a capacitor to set the soft-start timing.

The soft start works by limiting the inrush of current when the capacitors in the circuit are completely discharged. If the current were not limited by the soft start, the system would attempt to charge the capacitors instantly, potentially causing damage to the circuit and excessive switching of the MOSFETs on the primary side. Using a 470nF capacitor connected to the SS pin and tied to ground sets the soft start time to 256ms.

The resonance of the switching network is crucial in creating a functional LLC converter; if the resonance is off, the MOSFETs may end up turning on simultaneously, shorting the circuit, which would be catastrophic. The resonate tank is used to set the resonance of the LLC converter and is implemented in this design using split capacitors to achieve this. Using two smaller voltage-rated capacitors connected in series, less current is sent through each capacitor, as only half the RMS voltage is applied across them.

The resonance of the converter is affected by the load; the figure below shows the resonant curve of the reference converter under various loads. The higher the load, the higher the gain is for the converter, with the resonate frequency shifting slightly to the left. At lower loads, the gain decreases, and the resonate frequency shifts to the right. It is essential that the resonance remains on the left side, as shifting it too far to the right could cause the switching network to short, as previously mentioned.

Figure 8: Resonate curve in frequency domain

GD1 and GD2 are connected to the INA high side and INB low side of the U1 gate driver, respectively, and grounded through GND. Additionally, disable and other unused pins on U1 are grounded. VCCI, VDDA, and VDDB are connected to the same 12V input as U3 to supply power to both the primary and secondary sides of the gate driver. OUTA and OUTB connect to the gates of M1 and M2. The MOSFETS M1 and M2 are connected in series and will alternate when they switch on and off based on the input clock signal. The node that connects M1 and M2 is defined as HB_out, which is sent to the primary side of the transformer.

Components used:

- UCC21520DWR – Gate Driver
ο | 33ns propagation delay
ο | 8kVpk isolation
- IMBG65R050M2HXTMA1 – MOSFET
ο | Very low switching losses
ο | Vgs of 4.5V
- UCC25600DR
ο | Programable dead time
ο | Programable minimum switching frequency
ο | 50/50 duty cycle
ο | Over current protection

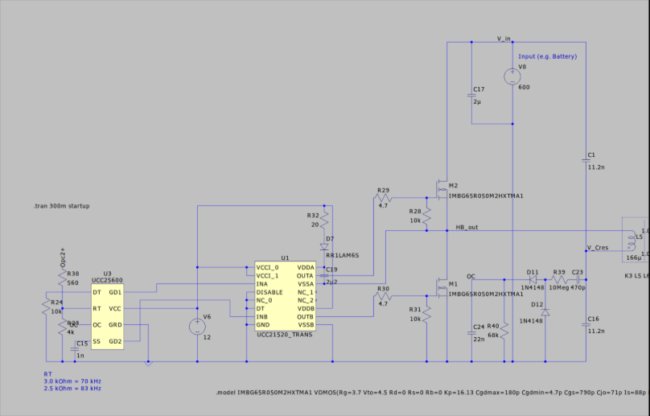
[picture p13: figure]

Figure 9: Primary Side

Secondary Side:

The secondary side is defined as the circuit that connects the transformer output, the secondary winding, to the load. The secondary side’s primary function is to rectify the output, 12-volt AC signal, into a stable, smooth 12-volt DC signal. It does this by sending the 12V AC signal from the transformer to a rectifier, which turns it into a 12V noisy DC signal. That signal then goes through an output filter to provide a cleaned up 12V DC signal. Additionally, the secondary side contains a voltage-controlled feedback circuit to provide galvanically isolated, proportional feedback to the control circuit. To debrief further we will cover each circuit below in more detail:

Rectifier:

The first circuit on the secondary side is the center-tapped full wave synchronous rectifier. The purpose of this circuit is once again to convert 12-volt AC to a rough 12-volt DC signal. A standard center tapped full wave rectifier is shown below, where the center-tap serves as the output to the load (high-side) and the ends of the transformer are tied to ground via diodes (termed low side). These diodes serve to rectify the AC signal. However, the main issue with using diodes or passive rectification in our application is that we have a relatively low-voltage, large current output, so the voltage drops, and power dissipation of the diodes becomes a significant problem and the bottleneck of the DC-DC converter.

Figure 11: Center-Tapped Full Wave Passive Rectifier

Figure 10: Block Diagram of Secondary Side

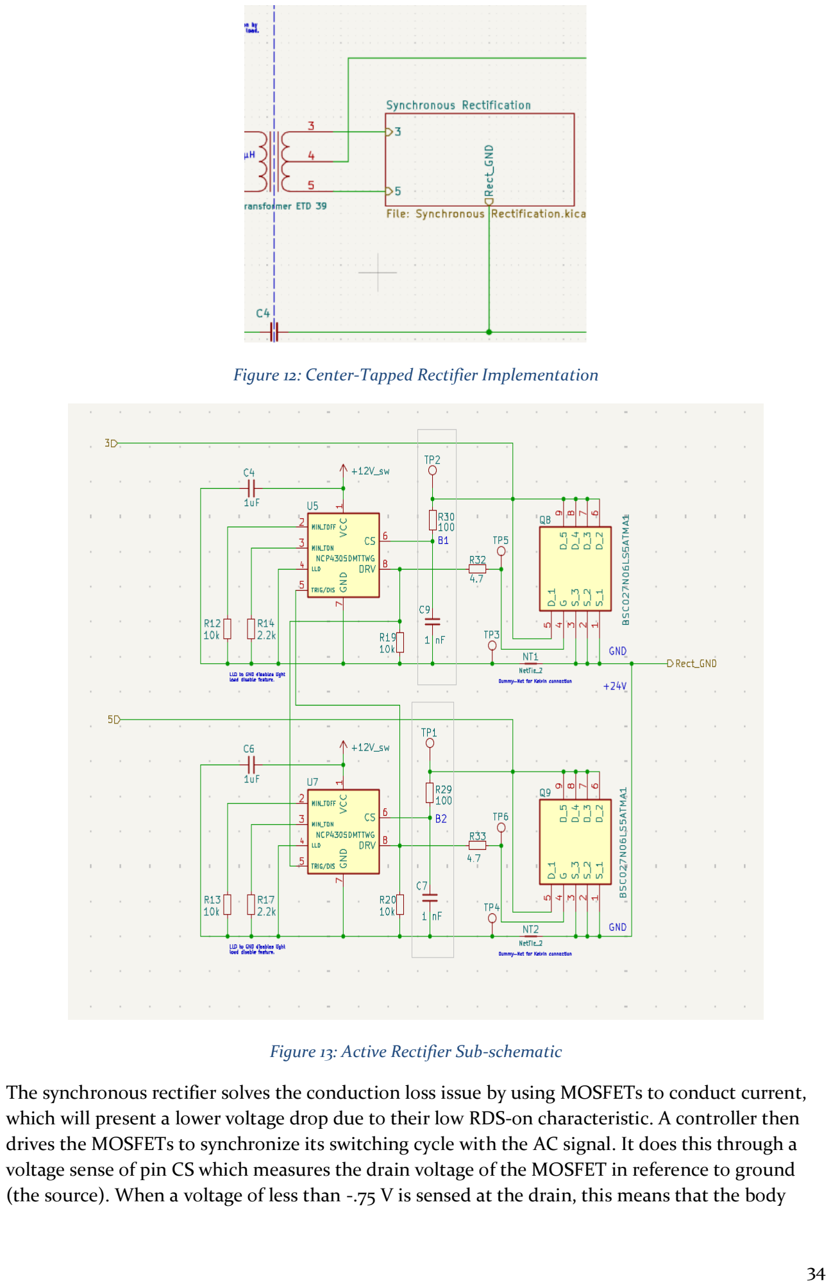
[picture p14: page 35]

Figure 12: Center-Tapped Rectifier Implementation

Figure 13: Active Rectifier Sub-schematic

The synchronous rectifier solves the conduction loss issue by using MOSFETs to conduct current, which will present a lower voltage drop due to their low RDS-on characteristic. A controller then drives the MOSFETs to synchronize its switching cycle with the AC signal. It does this through a voltage sense of pin CS which measures the drain voltage of the MOSFET in reference to ground (the source). When a voltage of less than -.75 V is sensed at the drain, this means that the body diode of the MOSFET is conducting (forward bias mode) and therefore, the MOSFET is switched on to provide a less resistive path and reduce conduction losses. When a voltage of nearly 0V is sensed at the drain, this means that the diode is now reverse-biased because the current is travelling in the opposite direction through the MOSFET's channel; therefore, the MOSFET is switched off to mock the reverse-bias behavior of a rectifier diode. Essentially, the MOSFET mimics the function of a diode with the added benefit of lower conduction loss.

Components:

- SR Controller: NCP4305DMTTWG
- MOSFET: BSC027N06LS5ATMA1
- RDS-ON = 4 mW
- C31 decoupling capacitor specified from datasheet
- R13 and C6 serve to properly trigger the CS pin (validated through testing)
- R42 sets minimum of-time period
- R38 sets the minimum on-time period

MOSFET Calculated Conduction Losses:

PCond = ID

2 × Rds−on = 3.6 W

Equation 1: MOSFET Conduction Losses

Output Filter:

The purpose of the output filter is to smooth the rectified, pulsating output waveform into a constant DC voltage/current, eliminating current and voltage ripple. This is done through a low-pass pi filter topology, with two shunt capacitors and a series of inductor. A pi filter is useful because it provides multiple stages of filtering. The first stage, which consists of five 15 μF capacitors in parallel (75 μF), provides a fast frequency response and filters out high-frequency noise/ringing. The next stage, the LC low-pass filter, contains a 0.8 μH inductor and two 2200 μF capacitors in parallel (4400 μF) to further smooth out the waveform to a constant DC voltage.

Figure 14: Output Filter Simulation

Figure 15: Output Filter Physical Implementation

When implemented into the system, we had a voltage ripple of around 7 mV and a current ripple of around 7 mA. The simulation results for the ripple current are shown below.

Figure 16: Voltage Ripple from SPICE Simulation

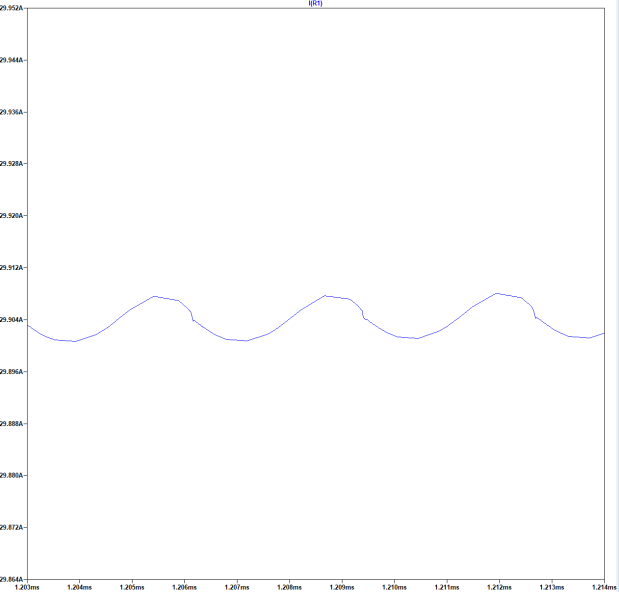
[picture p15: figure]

Figure 17: Current Ripple from SPICE Simulation

Transformer:

The purpose of the transformer is to step down the voltage from 600VAC to 12VAC and convert the current in the inverse ratio. This is done by using two ETD cores, with one gapped and the other not, and two separate wires wrapped around the ETD cores. In our case we used an ETD39 with a N87 material to reduce losses and maintain a small form factor. From here we used Remington Industries HF Litz wire 14awg (5X3/29/40) to make the coils; the size was chosen to allow proper amounts of current to flow without major cooling & for reduction of losses in the transformer windings. Lastly, an SLA printed bobbin will be used to encase the transformer to prevent windings and ETD cores from moving apart.

s =

AL
K1

1
K2

Equation 2: Transformer Air Gap Size Formula

AL =

Lp
N²

=

166000 nH
28²

= 211.73nH

Equation 3: Transformer Inductance Coefficient

s =

211.73
196

1
−0.734
= 0.90mm

Equation 4: Transformer Air Gap Calculation

The figure above shows the calculations used to determine the gap between UI cores to achieve a high enough magnetizing inductance, thereby avoiding the need for a series of inductors. The given values of Lp (magnetizing inductance) are from the Onsemi half bridge design spreadsheet, while K1 and K2 are from the datasheet of the UI cores. All this combined is used to calculate the center gap between the two UI cores.

The bobbin, as previously mentioned, is printed from temperature resistant SLA resin. The original bobbin design was an issue in construction because it had no guides for the LITZ wire resulting in massive deviations from our desired inductances. Due to these massive deviations, we added guides to a new revision of the bobbin to prevent the windings from moving during construction as shown in the figure below.

Figure 18: Final bobbin

The values that are required to have the transformer work efficiently with the rest of the circuit were given in the ONSEMI calculation excel sheet, the primary winding is meant to have a 166uH inductance value while the secondary windings (both) are meant to have a 56uH inductance value. By reaching these inductance values, the efficiency of the transformer stays high, the gain is minimized, and the leakage inductance is large enough to prevent the need for a power inductor. The windings, because of the transformer's tuning, are then glued to the bobbin to hold their desired inductance values. Likewise, the bobbin, once inserted onto the cores, is glued to prevent vibration and further variation in the inductance values. The transformer is then able to be placed on the board; however, the insulation used on the LITZ wire must be removed to conduct properly.

Power Supply:

Figure 19: Block Diagram of Power Supply

The purpose of the power supply is to power the overtemperature system, help with the fan voltage select, and power the feedback loop. The power supply starts with taking in the stepped down rectified voltage from the transformer. This voltage then gets stepped down via U3, a high efficiency step down converter to 3.7 Volts to charge the super capacitor C_start1. This is achieved by adjusting the voltage from the feedback pin via a voltage divider. The super capacitor can discharge the system startup for 100 seconds. It also acts as a battery as it takes the voltage from the feedback loop to keep the system running. U3 is an MP4541_SOP8-EP, and we are using its
common configuration provided by the datasheet.

FB Voltage: 1.0 V

Vout = 1.0 (1 +

27000
10000) = 3.7V

Equation 5: U3 Common Configuration Equation

Q7 and D8 are used for reversing current blocking. When Q7 is off, the inductor releases a kicked-up voltage then is rectified by D9. C64 C8 Stabilize voltage and provide instant current during switching. U4 is a boost converter that uses the super capacitor voltage to boost the voltage back up to 12V. This 12V is used for port 1 of the fan select and it is used to power the overtemperature system. C17 C18 provides smoother 12V. U2 is a low dropout voltage regulator; it takes the boosted 12V and converts it to a fixed 9V. This 9V is used to power the feedback loop.

Figure 20: First Section of Power Supply

Figure 21: Second Section of Power Supply

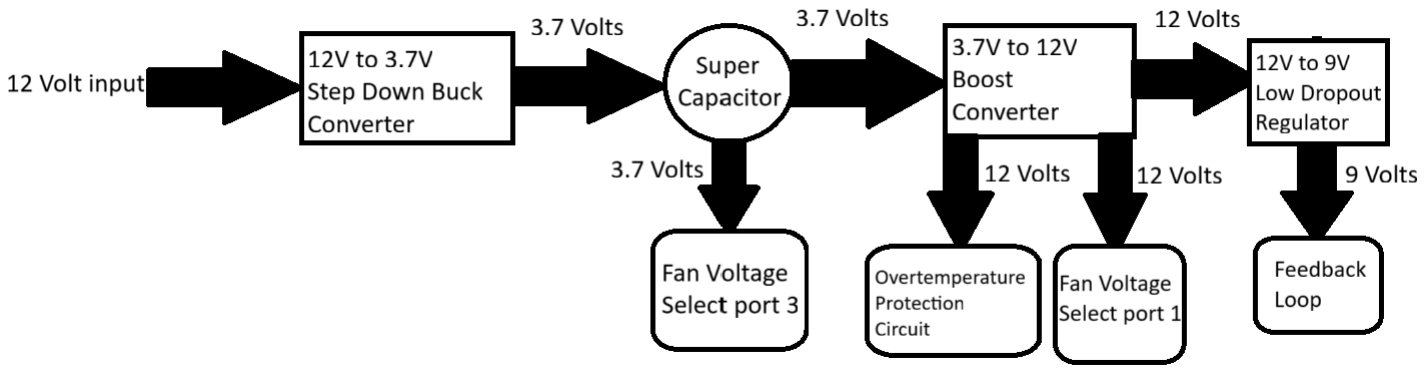
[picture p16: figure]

Figure 22: Power Supply Block Diagram

Overtemperature Protection:

The Overtemperature Protection system shuts down the device when the temperature surpasses the safe operating limit to prevent overheating. The Overtemperature Protection and Fan control are comprised of 2 op-amps. The Overtemperature control op-amp Vin+ is connected to a D10 diode that is connected to the op-amp output for latching. The Vin- is connected to a TH2, which uses the diode to measure the maximum temperature based on the parallel combination of the R36 = 4.7K resistor and parallel resistor. The TH2 impedance changes based on the combined parallel resistance and is converted to a temperature value measured in Celsius. TH2 is connected to the 2 parallel resistors. Right now, for R35 (330K) in parallel to the R36, the TH2 has a resistance of 1404 ohms, which is a temperature of 113.5 Celsius, which is measured as 106.9 Celsius due to noise on the op-amp signals.

The fan control circuit regulates the fan speed by adjusting the current or voltage following it. When the fan op-amp is on, the fan receives 5.9466 V which converts to 4784 Ohms which converts to 77 degrees Celsius. When the fan op-amp is off, the fan receives 6.0533 V which converts to 4617 Ohms which converts to 68 degrees Celsius.

Figure 23: Overtemperature Protection Circuit

4.3.3 Functionality

The 600V LLC converter is to be used in conjunction with low-load electric vehicles. In a low-load EV scenario, it is expected that the LLC converter could be plugged into an existing system (seen in figure 4) and convert the inverter-supply voltage down to a usable 12 volts for low-voltage electronics. The LLC converter would be able to power all electronics in a low-load scenario, and the user would simply need to activate an enabled button to turn it on.

Figure 24: 600VDC LLC Coverter Connection to Car

4.3.4 Areas of Challenge

All of our challenges in this project were in regard to technical progress and satisfying requirements. We were very successful in meeting user needs. The largest challenge that we ran into when designing our converter was concerning issues regarding the PCB print. Our first issue was that there was an extra pad included for a resistor that we had removed from our design. This was creating a break in our circuit which was hurting the results. To rectify this issue, we simply made a bridge between the pads with solder. Upon testing it after solving the issue, we found that the circuit was working as expected. Our next major issue was regarding a fuse that we had forgotten to add to the PCB footprint. To solve this problem, we ended up soldering it between two separate components that it should be connected to. We tested this solution to ensure it worked and found that the circuit functioned as expected. The last major issue that we ran into was regarding our transformer’s inductance. We were having a very hard time tuning it to get the correct leakage inductance. To solve this problem, we reached out to our faculty mentor for advice and ended up finding that by shortening the leads we were able to solve the issue.

4.4. Technology Considerations

There are two distinct technologies used in the LLC converter. The first is the type of MOSFETs used in the switching network that converts the HV DC to HV AC. The types of materials used in the MOSFETs can alter the efficiently, heat output, activation voltage, switching time, among other factors. The MOSFETs used in the design are standard Silicon based MOSFETs that use dopants such as Boron or Phosphorus. However other MOSFETs can be used that utilize more cutting-edge martials such as Gallium Nitride (GaN) or Silicon Carbine (SiC) which offer benefits in these key areas, however they can be more challenging and expensive to implement compared to standard Si MOSFETs. For the designs first implementation, standard Si MOSFETs will be used to verify functionality with later revisions possibly adding GaN MOSFETs if time and budget allow it.

The other technology is in the rectification of LV AC to LV DC. There are two possible solutions, either using passive rectification utilizing diodes or using active rectification which utilize MOSFETs that operate as a diode. Passive rectification has some advantages such as its simplicity to implement. It can have some drawbacks such as it can be less efficient and can break down and no longer function if the specifications don't meet the requirements. Active rectification on the other hand is more complex to implement requiring additional circuitry to control the MOSFETs but tend to handle more current and have overall better efficiency, but thermals are still a concern especially with the expected output current of 30A so cooling will be an additional consideration. With our design, active rectification is planned to be used due to its overall better efficiency and the lack of diodes that are available within our needed specifications. However, with active rectification, additional consideration will be on how to cool the MOSFETs as keeping the FETs cool will allow for more current to pass through them. If the thermal management is inadequate, then the converter will not operate as it is designed to.

4.5. Assembly

4.5.1 PCB

After designing the converter, we ordered the board through JLC PCB with assembly of most of the SMD components. However, there were still numerous components that we had to manually solder ourselves. Note that we found several issues with the quality of JLC assembly as a few solder joints were faulty and even some components had incorrect footprints. Figure 22 below shows our disassembled board while Figure 23 showcases our assembled board without the transformer.

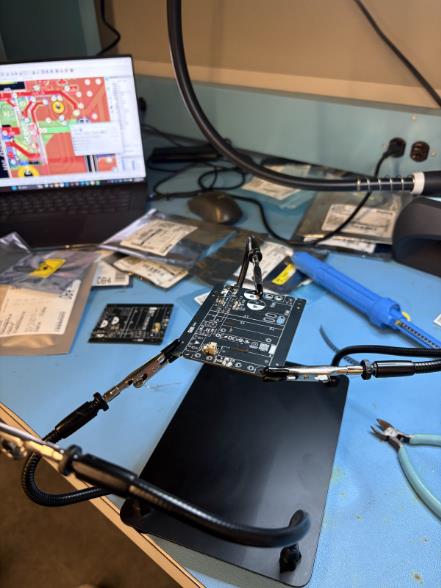
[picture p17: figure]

Figure 25: Unassembled Board

Figure 26: Assembled Board

4.5.2 Transformer

Concurrent with the assembly of the PCB, the transformer was being assembled and tested. The transformer was incredibly finicky and highly sensitive – simply touching the windings with bare hands caused an 11% difference in inductance values. Due to the transformer being so sensitive and having a litany of parameters attached to proper assembly, it took significantly longer than expected.

Twenty eight turns were applied in clockwise order to the primary side of the bobbin, where there was two wires wrapped once clockwise to the secondary side of the bobbin. The windings were then glued to the bobbin and the transformer was then glued together with clamping force applied.

Figure 27: Transformer before being glued

4.5.3 Completed Design

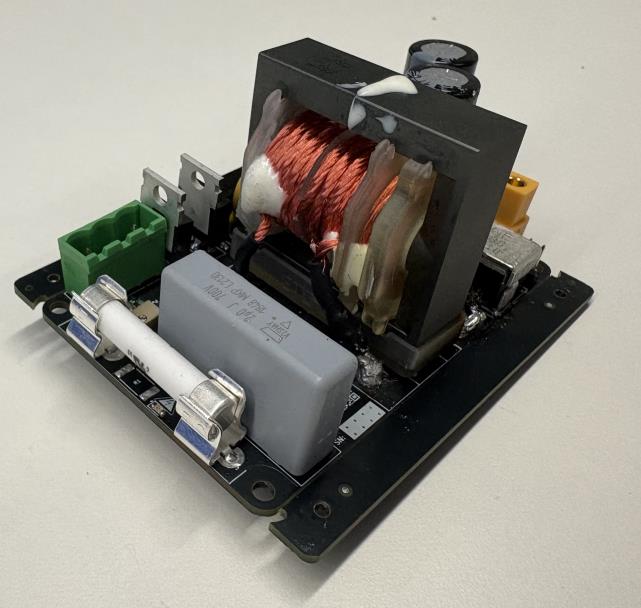
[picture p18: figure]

Figure 28: Primary side Isometric View of Completed LLC Converter

Figure 29: Top View of Completed LLC Converter

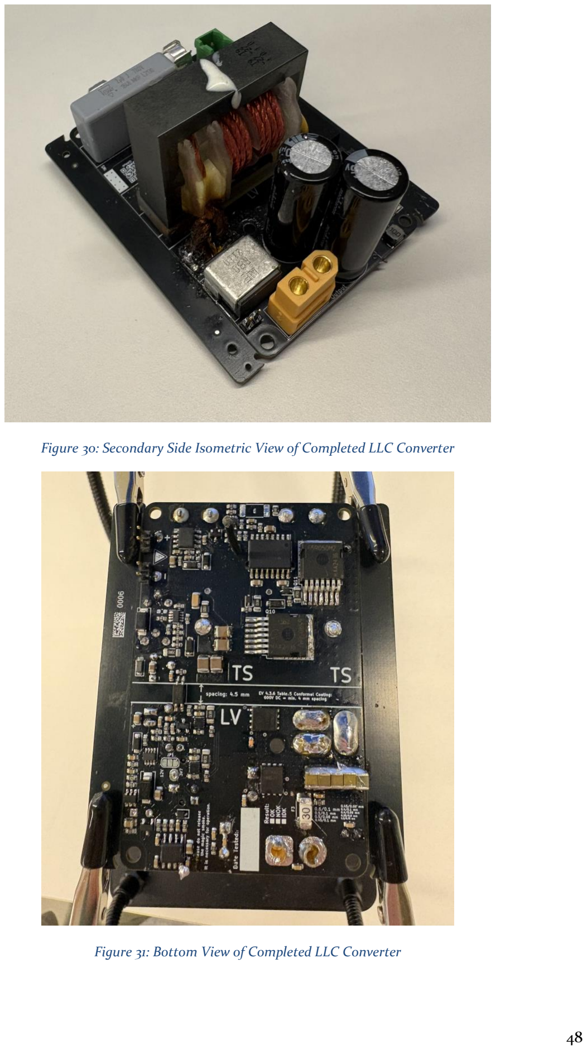
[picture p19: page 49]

Figure 30: Secondary Side Isometric View of Completed LLC Converter

Figure 31: Bottom View of Completed LLC Converter

## 5. Simulation

5.1. Basic Passive and Active Load Tests

Before we assembled the board we created an LTSpice simulation to verify the design and functionality of the converter the full SPICE simulation Model can be seen below.

Figure 32: SPICE Simulation Model

The results displayed below showcase the converter's response to several passive loads. We first simulated the converter with a 144 Watt passive load and then a 360 Watt passive load (the maximum load that we have rated the converter for). Notice that simulated responses to the passive loads appear almost identical for both, stabilizing after about .5 milliseconds with marginal overshoot and settling time. The 144-watt passive load settles at about 11.98 volts, while the 360-watt passive load settles at about 11.95 volts.

Figure 33: Results Using 600 Vin and 144 Watt Passive Load (1 ohm resistor)

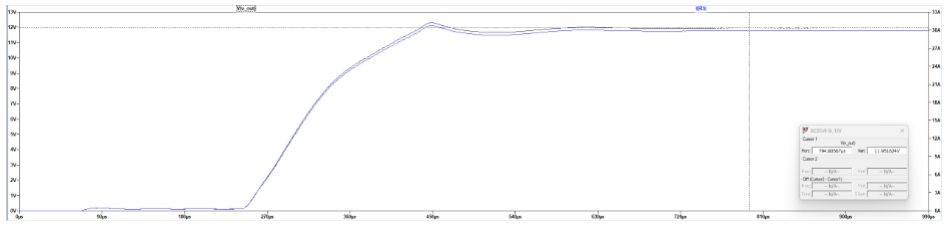
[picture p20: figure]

Figure 34: Results Using 600 Vin and 360 Watt Passive Load (.4 Ohms Resistor)

Next, we then tested the output line regulation. We did this by using a Vin of 430 volts, the minimum possible voltage of the tractive system battery at its lowest state of charge. As shown in the results, the output voltage ranges from 11.86 to 11.95 volts, within the required tolerance.

Figure 35: Results Using 430 Vin and 360 Watt Passive Load

The next set of results shows the converters' step response to an active load that pulses from 11 to 11.8 volts. As shown in the graph below, the converter responds well within a millisecond. However, it should be noted that Vin has a strong impact on the system's response, as it responds more effectively at lower input voltages, as you can see from the contrast between the two figures
below. Note that there is no standard that our client has required us to hit for response times to loads, but it is good practice to ensure the response time is reasonable (within a few milliseconds at most). This is also a metric that we can improve in future iterations as our client continues to develop their EV.

Figure 36: Results Using 240 Watt Active Load Step (Voltage Source with 48 mohm series resistance) Vin = 600 volts

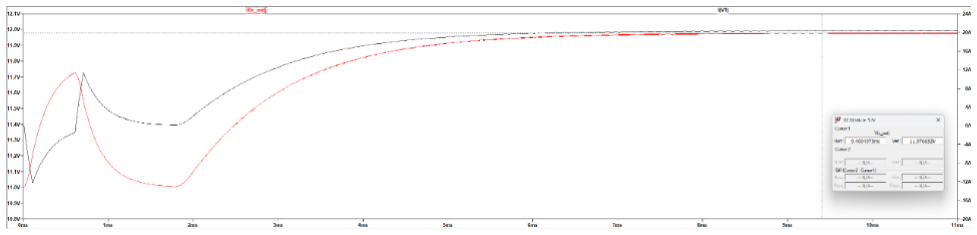
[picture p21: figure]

Figure 37: Results Using 240 Watt Active Load Step (Voltage Source with 48 mohm series resistance) Vin = 400 volts

5.2. Transient Response

After confirming that the overall converter simulation was functioning correctly, we decided to conduct more rigorous testing. To obtain a more accurate estimate of the system's response time, we simulated its transient response using a more elaborate test bench. As shown in
the figure below, we created a dynamic load switching network using an array of voltage-controlled switches. We were then able to create a waveform to simulate load
stepping. where the largest load is 576 watts, the intermediate load is 384 watts, and
the smallest load is 192 watts. This allowed us to test the transient response of the converter just above its maximum load at 360 watts. Note that the input voltage was set to 600 volts, the maximum voltage, for each of these simulations.

Figure 38: Dynamic Load Transient Response Testbench

We then measured the output voltage and current to obtain transient response performance metrics of the converter. The first figure below is the load step-down transient response of the converter. Note that the current waveforms in the figures for step-down are negative due to the way LTSPICE interprets the direction, but this was corrected for the step-up figures.

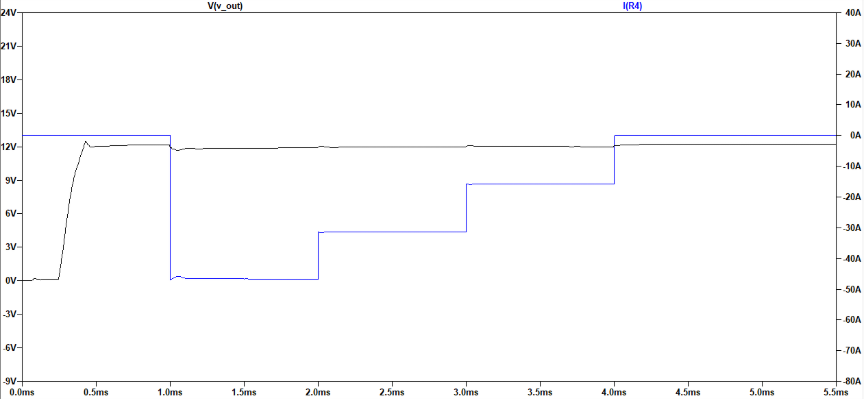
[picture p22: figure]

Figure 39: Step-Down Transient Response

Looking closer at the current waveform below, the second load step, where it reaches 384 watts, is close to the maximum output current of the converter. At this point, we can observe a small amount of oscillation in the current. However, this is practically negligible as this is only an overshoot of about .2%, well within the 2% settling criterion standard.

Figure 40: Current Transient Response, 384 Watts, Load Step Down

Looking closer at the voltage waveform, we once again see a very strong transient response to the change in load current. The max overshoot of the voltage is fractions of a percent, as shown below.

Figure 41: Voltage Transient Response, 384 Watts, Step Down

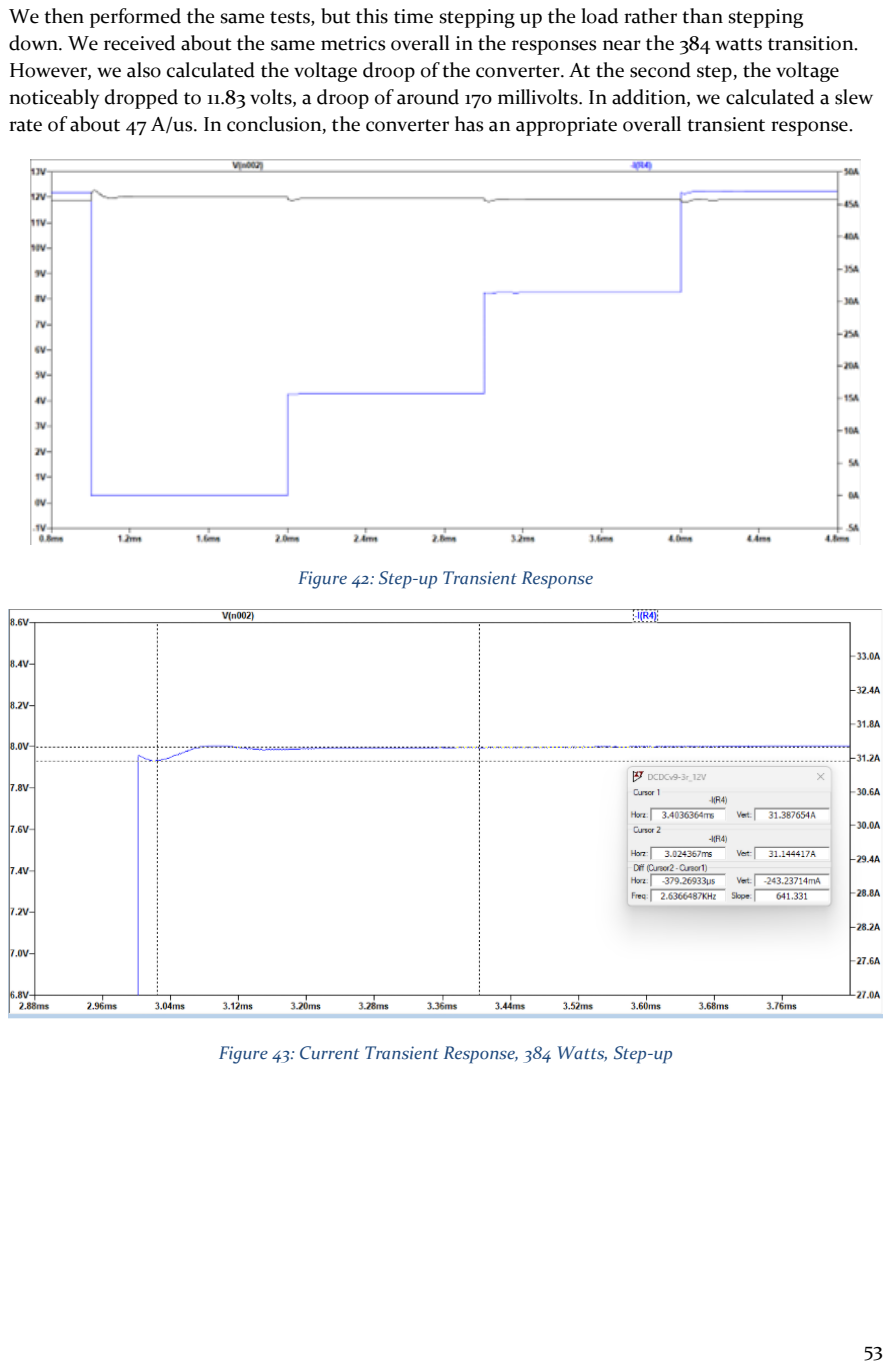
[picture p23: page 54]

We then performed the same tests, but this time stepping up the load rather than stepping
down. We received about the same metrics overall in the responses near the 384 watts transition. However, we also calculated the voltage droop of the converter. At the second step, the voltage noticeably dropped to 11.83 volts, a droop of around 170 millivolts. In addition, we calculated a slew rate of about 47 A/us. In conclusion, the converter has an appropriate overall transient response.

Figure 42: Step-up Transient Response

Figure 43: Current Transient Response, 384 Watts, Step-up

Figure 44: Current Slew Rate (47 A/us)

Figure 45: Voltage Droop at Transient, 384 watts

5.3. Power Dissipation/Losses

In the next test, we wanted to obtain the efficiency of the system. However, in order to get a better estimate of the rectifier losses, we created a diode model to simulate the conduction losses of
the synchronous rectifier MOSFET. This was done by creating an ideal diode with an RDS-on of approximately 4 milliohms, as shown in the figure below.

Figure 46: Synchronous Rectifier Conduction Loss Diode Model

This was done by measuring the average input power of the system and comparing it to the output power. The figure below showcases the instantaneous input power (blue) and output power (black). We then took the average of each waveform as shown below. The average input power was found to be 368 watts, while the average output power was 359.6 watts. Therefore, the total power dissipated throughout the system was 8.4 watts, and the converter's
efficiency is 97.7%. However, this is once again an ideal model, so we expect to see much less efficiency during physical testing.

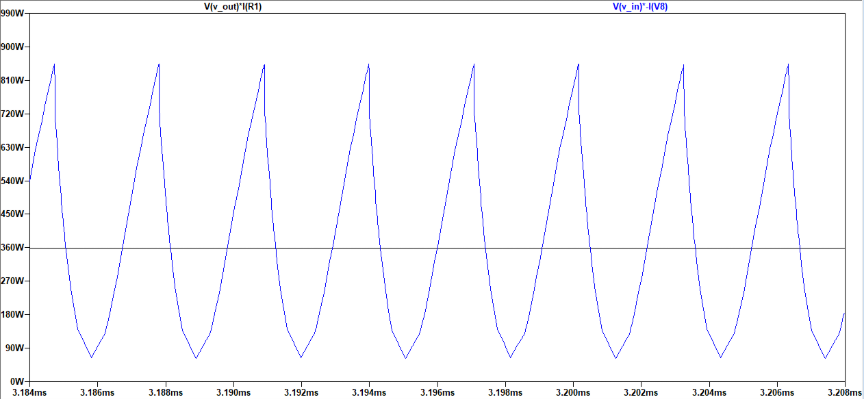
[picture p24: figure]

Figure 47: Instantaneous Input and Output Power

Figure 48: Average Input (Left) and Output Power (Right)

Finally, we decided to simulate the losses across individual components to investigate the major sources of power dissipation. This also allowed us to evaluate whether each component could tolerate the power dissipation. The following figures showcase the power dissipation across each individual component in the simulation: the half-bridge diodes, rectifier diodes, and output filter components. Note that since the transformer model did not account for core losses, we did not measure any power dissipation across the transformer. Overall, each component saw a tolerable amount of power dissipation.

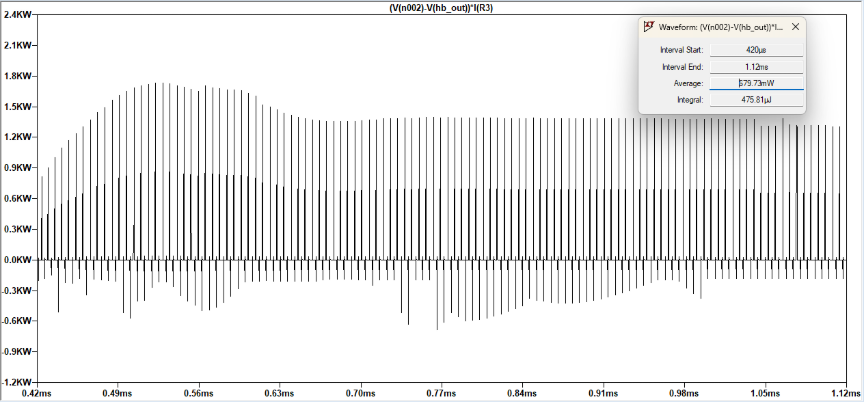
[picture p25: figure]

Figure 49: Conduction Losses Across M2, Pull-Up Half Bridge N-Channel MOSFET (679 mW)

Figure 50: Conduction Losses Across M1, Pull-Down Half Bridge N-Channel MOSFET (88 mW)

Figure 51: D1 Synchronous Rectifier Diode Power Dissipation (2.08 W)

Figure 52: D2 Synchronous Rectifier Diode Power Dissipation (2.27 W)

Figure 53: L8 Output Filter Inductor Power Dissipation (884mW)


Figure 54: C22 Output Filter Capacitor Power Dissipation (863mW)

5.4. Conclusions regarding full-system simulation

Although these simulations provide a good baseline for overall function, this simulation does not incorporate a few essential elements of the system. Most importantly, it does not include our synchronous rectifier, which is a crucial component and a common failure point in this design. We attempted to build a simulation for the synchronous rectifier, but we were unable to find the proper SPICE models for the components used. Additionally, ringing and EMI issues often plague switching converters, and these issues will be uncovered as we begin physical testing, as outlined in the test plan in the unit test section.

5.5. Precharge Simulation

Below is a simulation of the Precharge voltage curve, where the voltage show in the DC-link capacitor. The objective is to get the capacitor to charge as fast as possible with as small of a resistor as possible.

Figure 55: Precharge results for a 600VDC source
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

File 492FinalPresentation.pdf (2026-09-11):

# 600-12 Volt DC-DC Converter

Team: sdmay26-45

Client: Formula SAE Team

Advisor: Professor Cheng Huang

Members: Caleb Rezmer, Hunter Kanne, Andrew Chandler, Drew Bixler, Diego Rivera, Wesley Mao

# Team

Andrew | Caleb Rezmer
Chandler
Hunter | Diego Rivera
Kanne

Drew
Bixler

Wesley Mao

# Problem Statement


Problem: The Iowa State Formula SAE team is currently designing an electric race car; however, they needed a way to supply substantial power to their low-voltage systems.

Solution: Design an efficient DC-DC converter to power the low-voltage systems from the high-capacity tractive system battery.

https://www.facebook.com/photo/?fbid=1065808692257333&set=pcb.1065809028923966

600 Volts | 12 Volts

## - Input voltage of 400-600 volts

## - Stable 12-volt output

## - Can supply at least 30 amps of current

## - Efficiency > 90%

## - Galvanic Isolation

## - Complies with FSAE design requirements

### oVoltage separation spacing (4mm)

## oDischarge rates

https://www.pennelectricracing.com/what-is-fsae

# Requirements

# Approach

After Researching….

- Decided on Half-bridge LLC Converter Topology due to the following factors:
- Efficiency
- Galvanic Isolation
- Wide Load and Input Voltage range
- Small footprint
- Interest and complexity (state-of-the-art)
- Found an open-source GitHub repository from a German Formula team that has been developing an LLC converter for several years:
- Converts 400-600 Vin to 24 volts
- Maximum output current of 20 amp
- Based on our team’s level of experience and confidence in power electronics design, we decided to reference the design and create a 600:12 volt, 30 amp revision

https://www.electroniclinic.com/what-is-a-voltage-divider-or-potential-divider-formula-and-practical-uses/

# Timeline

Research; Design; Simulation; Layout; Ordering; -Main Simulation -Precharge Simulation -Attempted SR simulation; -Implement new footprints -Modified existing layout; Timeline:; Implementation; Regression; System; Testing; Unit; Assembly; -High Voltage Testing -Load Testing -Input Range Testing; -Adjustments made (Supercap removed) -Tuned switching frequency; -Tested Board With Low Voltage -Isolation Tested Transformer

-Researched DC-DC
Converters
-Decide on converter
topology

-Discussed design with
client and previous team
-Specified new
components

-Created project budget
-Make tradeoffs
-Negotiated cost split
-Acquired sponsor

-Tested converter in car
-Added parallel
functionality with low
voltage battery

-Constructed and Tuned
Transformer To Specs
-Assembled PCB

# High-Level Design

- The design of the LLC converter is split up into several
subsystems:
oPre-Charge
oSwitching Network
oResonant tank
oTransformer
oRectifier
oOutput Filter
oControl Loop
oPower Supply

https://media.monolithicpower.com/wysiwyg/Articles/A-0028_fig1.png

Basic LLC Converter Topology

# High-Level Design


High-Level System Flowchart | High-Level System Schematic

# Switching Network and Resonant Tank

- Switching network converts DC input to a square wave
- Resonant tank converts square wave into AC sinusoidal wave
- This allows transformer to efficiently
step 600 V 12 V
- The minimum switching frequency is set to maximize converter efficiency and effective converter input range


Switching Network
and Resonant Tank
Diagram

# Control Loop

### - Regulates the output voltage at 12 volts despite changes in input voltage and load

### - If output voltage exceeds 12 V the switching frequency increases to lower the output voltage vice versa

### - Feedback Loop:

oProvides autonomous output regulation oPowered by output voltage so no external power needed

10 Control Loop Diagram

# Transformer

## - The Transformer steps down AC voltage by a fixed ratio

## - Our design has a transformer with 28:1 windings with a gap of 1mm oReference design has 28:2 with a 1mm gap


Transformer parts

# Rectifier and Output Filter
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

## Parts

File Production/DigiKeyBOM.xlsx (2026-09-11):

Country of Origin may be different at time of shipment.
The HTSUS and ECCN information shown is for informational purposes only and is not a representation or warranty as to the accuracy or reliability of these classifications. All information is provided "as is" and is subject to change without notice. Any use made of the information provided is without recourse to Digi-Key and at the user's risk.
Quantity | Manufacturer Part Number | Manufacturer Name | Description | Lead Time | Availability | Stock Status | Customer Reference | Requested Part Number | Lead Weeks | Datasheet | Reference Designator | US Import Tariff | Note | Part Status | RoHS Status | Moisture Sensitivity Level (MSL) | ECCN | HTSUS | Country of Origin | Environmental Information | Original Part numbers | Image | Product Notes
2 | HMJ107BB7104KAHT | Taiyo Yuden | CAP CER 0.1UF 100V X7R 0603 |  | 60,644 | In Stock |  | 587-4481-1-ND | 14 |  |  | N/A |  | Active | ROHS3 Compliant | 1 (Unlimited) | EAR99 | 8532.24.0020 | South Korea |  | 587-4481-1-ND | https://mm.digikey.com/Volume0/opasdata/d220001/medias/images/331/Taiyo-Yuden-0603-%281608-Metric%29.jpg
2 | UHW1V222MHD | Nichicon | CAP ALUM 2200UF 20% 35V RADIAL |  | 7,807 | In Stock |  | 493-6871-ND | 29 | https://www.nichicon.co.jp/english/series_items/catalog_pdf/e-uhw.pdf |  | N/A |  | Active | ROHS3 Compliant | Not Applicable | EAR99 | 8532.22.0020 | Japan |  | 493-6871-ND | https://mm.digikey.com/Volume0/opasdata/d220001/medias/images/2587/UHW%20Series%2037.50mm.JPG
1 | UMK107ABJ474KA-T | Taiyo Yuden | CAP CER 0.47UF 50V X5R 0603 |  | 286,281 | In Stock |  | 587-3171-1-ND | 14 | https://mm.digikey.com/Volume0/opasdata/d220001/medias/docus/1852/UMK107ABJ474KA-T_SS.pdf |  | N/A |  | Active | ROHS3 Compliant | 1 (Unlimited) | EAR99 | 8532.24.0020 | Japan |  | 587-3171-1-ND | https://mm.digikey.com/Volume0/opasdata/d220001/medias/images/331/Taiyo-Yuden-0603-%281608-Metric%29.jpg
4 | 885342208005 | Würth Elektronik | CAP CER 470PF 500V X7R 1206 |  | 2,077 | In Stock |  | 732-12110-1-ND | 26 | https://www.we-online.com/components/products/datasheet/885342208005.pdf |  | N/A |  | Active | ROHS3 Compliant | 1 (Unlimited) | EAR99 | 8532.24.0020 | Taiwan | https://mm.digikey.com/Volume0/opasdata/d220001/medias/docus/744/Certificate_of_Compliance_ROHS.pdf | 732-12110-1-ND | https://mm.digikey.com/Volume0/opasdata/d220001/medias/images/739/1206-%283216-Metric%29-2%2C20mm_BN.jpg
1 | C0603C470J1HACTU | KEMET | CAP CER 47PF 100V X8R 0603 |  | 16,697 | In Stock |  | 399-C0603C470J1HACTUCT-ND | 13 | https://www.yageogroup.com/content/datasheet/asset/file/KEM_C1007_X8R_ULTRA_150C_SMD |  | N/A |  | Active | ROHS3 Compliant | 1 (Unlimited) | EAR99 | 8532.24.0020 | Mexico |  | 399-C0603C470J1HACTUCT-ND | https://mm.digikey.com/Volume0/opasdata/d220001/medias/images/5352/0603-%281608-Metric%29-Ceramic-Capacitor.jpg
1 | VY1332M59Y5UQ63V0 | Vishay Beyschlag/Draloric/BC Components | CAP CER 3300PF 760VAC Y5U RADIAL |  | 9,452 | In Stock |  | BC2377-ND | 12 | https://www.vishay.com/docs/28537/vy1series.pdf |  | May apply on shipments to the U.S. |  | Active | ROHS3 Compliant | Not Applicable | EAR99 | 8532.23.0060 | China |  | BC2377-ND | https://mm.digikey.com/Volume0/opasdata/d220001/medias/images/632/VY1332M59Y5UQ63V0.JPG
1 | R76UI22205050J | KEMET | FILM, RADIAL, PULSE, DOUBLE META |  | 1,661 | In Stock |  | 399-R76UI22205050J-ND | 28 | https://www.yageogroup.com/content/datasheet/asset/file/KEM_F3033_PHE450 |  | May apply on shipments to the U.S. |  | Active | ROHS3 Compliant | Not Applicable | EAR99 | 8532.25.0030 | China |  | 399-R76UI22205050J-ND | https://mm.digikey.com/Volume0/opasdata/d220001/medias/images/2864/MFG_R76_Series.jpg
8 | 885342206003 | Würth Elektronik | CAP CER 1000PF 250V X7R 0603 |  | 11,777 | In Stock |  | 732-12184-1-ND | 26 | https://www.we-online.com/components/products/datasheet/885342206003.pdf |  | N/A |  | Active | ROHS3 Compliant | 1 (Unlimited) | EAR99 | 8532.24.0020 | Taiwan | https://mm.digikey.com/Volume0/opasdata/d220001/medias/docus/744/Certificate_of_Compliance_ROHS.pdf | 732-12184-1-ND | https://mm.digikey.com/Volume0/opasdata/d220001/medias/images/735/0603-%281608-Metric%29-0%2C95mm_BN.jpg
5 | CL10B105KB9VPJC | Samsung Electro-Mechanics | CAP CER 1UF 50V X7R 0603 |  | 40,757 | In Stock |  | 1276-CL10B105KB9VPJCCT-ND | 31 | https://mm.digikey.com/Volume0/opasdata/d220001/medias/docus/5458/CL10B105KB9VPJC_Spec.pdf |  | N/A |  | Active | ROHS3 Compliant | 1 (Unlimited) | EAR99 | 8532.24.0020 | South Korea |  | 1276-CL10B105KB9VPJCCT-ND | https://mm.digikey.com/Volume0/opasdata/d220001/medias/images/2537/Ceramic-Capacitor-CL-Series.jpg
3 | C0603C223K1RACTU | KEMET | CAP CER 0.022UF 100V X7R 0603 |  | 276,517 | In Stock |  | 399-C0603C223K1RACTUCT-ND | 15 | https://www.yageogroup.com/content/datasheet/asset/file/KEM_C1002_X7R_SMD |  | N/A |  | Active | ROHS3 Compliant | 1 (Unlimited) | EAR99 | 8532.24.0020 | Mexico |  | 399-C0603C223K1RACTUCT-ND | https://mm.digikey.com/Volume0/opasdata/d220001/medias/images/4322/cut-tape-render.jpg
3 | C0603C103K2RECTU | KEMET | CAP CER 10000PF 200V X7R 0603 |  | 2,918 | In Stock |  | 399-14173-1-ND | 13 | https://www.yageogroup.com/content/datasheet/asset/file/KEM_C1090_X7R_ESD |  | N/A |  | Active | ROHS3 Compliant | 1 (Unlimited) | EAR99 | 8532.24.0020 | Mexico |  | 399-14173-1-ND | https://mm.digikey.com/Volume0/opasdata/d220001/medias/images/5352/0603-%281608-Metric%29-Ceramic-Capacitor.jpg
4 | C1210C562JDGACAUTO | KEMET | CAP CER 5600PF 1KV C0G/NP0 1210 |  | 7,748 | In Stock |  | 399-C1210C562JDGACAUTOCT-ND | 21 | https://content.kemet.com/datasheets/KEM_C1080_C0G_HV_AUTO_SMD.pdf |  | N/A |  | Active | ROHS3 Compliant | 1 (Unlimited) | EAR99 | 8532.24.0020 | Mexico |  | 399-C1210C562JDGACAUTOCT-ND | https://mm.digikey.com/Volume0/opasdata/d220001/medias/images/2934/MFG_C1206C123JCGACAUTO.jpg
3 | TMK212BBJ106KG-T | Taiyo Yuden | CAP CER 10UF 25V X5R 0805 |  | 1,115,450 | In Stock |  | 587-2985-1-ND | 13 | https://mm.digikey.com/Volume0/opasdata/d220001/medias/docus/4888/TMK212BBJ106KG-T_SS.pdf |  | N/A |  | Active | ROHS3 Compliant | 1 (Unlimited) | EAR99 | 8532.24.0020 | Malaysia |  | 587-2985-1-ND | https://mm.digikey.com/Volume0/opasdata/d220001/medias/images/331/Taiyo-Yuden-0805-%282012-Metric%29.jpg
6 | CL21A226MAYNNNE | Samsung Electro-Mechanics | CAP CER 22UF 25V X5R 0805 |  | 814,774 | In Stock |  | 1276-CL21A226MAYNNNECT-ND | 31 | https://mm.digikey.com/Volume0/opasdata/d220001/medias/docus/339/CL21A226MAYNNNE_Spec.pdf |  | May apply on shipments to the U.S. |  | Active | ROHS3 Compliant | 1 (Unlimited) | EAR99 | 8532.24.0020 | China | https://www.samsungsem.com/global/support/certificate/product-stewardship.do | 1276-CL21A226MAYNNNECT-ND | https://mm.digikey.com/Volume0/opasdata/d220001/medias/images/2537/Ceramic-Capacitor-CL-Series.jpg
1 | VMF256M3R8 | Cornell Dubilier Knowles | CAP LITH HYBRID 25F 20% 3.8V T/H |  | 1,055 | In Stock |  | 338-VMF256M3R8-ND | 26 | https://www.cde.com/resources/catalogs/VMF.pdf |  | May apply on shipments to the U.S. |  | Active | ROHS3 Compliant | Not Applicable | EAR99 | 8532.29.0040 | China | https://www.cde.com/resources/ROHS/CDE-Regulatory-Declaration.pdf | 338-VMF256M3R8-ND | https://mm.digikey.com/Volume0/opasdata/d220001/medias/images/2642/MFG_LIC_Rad.jpg
1 | APTD1608LSECK/J4-PF | Kingbright | LED ORANGE CLEAR 2SMD |  | 10,562 | In Stock |  | 754-1946-1-ND | 8 | https://www.kingbrightusa.com/images/catalog/SPEC/APTD1608LSECK-J4-PF.pdf |  | May apply on shipments to the U.S. |  | Active | ROHS3 Compliant | 3 (168 Hours) | EAR99 | 8541.41.0000 | China | https://www.KingbrightUSA.com/webimages/certificate/Kingbright%20RoHS%20CoC.PDF|https://www.kingbrightusa.com/webimages/certificate/REACH.pdf | 754-1946-1-ND | https://mm.digikey.com/Volume0/opasdata/d220001/medias/images/6348/MFG_APTD1608.jpg
3 | VS-E7FX0212-M3/I | Mitsubishi Electric Europe B.V. | DIODE STANDARD 1200V 2A DO219AB |  | 5,000 | In Stock |  | 112-VS-E7FX0212-M3/ICT-ND | 15 | https://www.vishay.com/docs/97162/vs-e7fx0212-m3.pdf |  | May apply on shipments to the U.S. |  | Active | ROHS3 Compliant | 1 (Unlimited) | EAR99 | 8541.10.0080 | China |  | 112-VS-E7FX0212-M3/ICT-ND | https://mm.digikey.com/Volume0/opasdata/d220001/medias/images/5789/112%7EDO219AB%28SMF%29%7E%7E2-View-2.jpg
4 | 1N4448WQ-7-F | Diodes Incorporated | DIODE STANDARD 75V 250MA SOD123 |  | 9,040 | In Stock |  | 1N4448WQ-7-FDICT-ND | 12 | https://www.diodes.com/assets/Datasheets/1N4448W.pdf |  | May apply on shipments to the U.S. |  | Active | ROHS3 Compliant | 1 (Unlimited) | EAR99 | 8541.10.0070 | China | https://mm.digikey.com/Volume0/opasdata/d220001/medias/docus/6731/Diode%20RoHS3%20REACH%20247%20Jan%202025%20Statement.pdf | 1N4448WQ-7-FDICT-ND | https://mm.digikey.com/Volume0/opasdata/d220001/medias/images/5753/31%7ESOD123%7E%7E2-View-2.jpg
3 | CDSOD323-T12 | Bourns Inc. | TVS DIODE 12VWM 28.3VC SOD323 |  | 9,962 | In Stock |  | CDSOD323-T12CT-ND | 22 | https://www.bourns.com/docs/Product-Datasheets/CDSOD323-TxxC.PDF |  | N/A |  | Active | ROHS3 Compliant | 1 (Unlimited) | EAR99 | 8541.10.0080 | United Kingdom | https://mm.digikey.com/Volume0/opasdata/d220001/medias/docus/6657/Bourns%20REACH%20247%20Jan%202025%20Statement.pdf|https://www.bourns.com/docs/rohs-cofc/coc_diode.pdf?sfvrsn=43f5f37c_10 | CDSOD323-T12CT-ND | https://mm.digikey.com/Volume0/opasdata/d220001/medias/images/4850/353_SOD-323.jpg
2 | SS1H10-M3/61T | Vishay General Semiconductor - Diodes Division | DIODE SCHOTTKY 100V 1A DO214AC |  | 8,999 | In Stock |  | SS1H10-M3/61TGICT-ND | 15 | https://www.vishay.com/docs/88747/ss1h9.pdf |  | May apply on shipments to the U.S. |  | Active | ROHS3 Compliant | 1 (Unlimited) | EAR99 | 8541.10.0080 | China |  | SS1H10-M3/61TGICT-ND | https://mm.digikey.com/Volume0/opasdata/d220001/medias/images/6163/112%7EDO214AC-SMA%7E%7E2.jpg
1 | 0ADBC1600-BE | Bel Fuse Inc. | FUSE CERM 1.6A 1KVAC 1KVDC 3AB |  | 609 | In Stock |  | 5923-0ADBC1600-BE-ND | 11 | https://belfuse.com/media/datasheets/products/circuit-protection/ds-cp-0adbx-series.pdf |  | May apply on shipments to the U.S. |  | Active | ROHS3 Compliant | 1 (Unlimited) | EAR99 | 8536.10.0040 | China | https://www.belfuse.com/resources/quality-center/quality-documents|https://www.belfuse.com/media/documents/quality/bel-fuse/REACH-Statement.pdf | 5923-0ADBC1600-BE-ND | https://mm.digikey.com/Volume0/opasdata/d220001/medias/images/778/0ADBC-Series.jpg
1 | 0154.500DR | Littelfuse Inc. | FUSE BRD MT 500MA 125VAC/VDC SMD |  | 3,661 | In Stock |  | F1220CT-ND | 23 | https://www.littelfuse.com/assetdocs/littelfuse-fuse-154-series-data-sheet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 |  | N/A |  | Active | ROHS3 Compliant | 1 (Unlimited) | EAR99 | 8536.10.0040 | Philippines | https://www.littelfusebusinesscenter.com/LFWeb/rohs_upload/RoHS_Certificate_of_Compliance/CoC_RoHS9_0154.500DR_04-16-2019.pdf | F1220CT-ND | https://mm.digikey.com/Volume0/opasdata/d220001/medias/images/2478/154%5E154T-Omni-Blok-Series-White.jpg
1 | CB61F30A-TR1 | Eaton - Electronics Division | FUSE BOARD MOUNT 30A 72VDC 2SMD |  | 5,900 | In Stock |  | 283-CB61F30A-TR1CT-ND | 19 | https://www.eaton.com/content/dam/eaton/products/electronic-components/resources/data-sheet/eaton-cb61f-surface-mount-brick-fuses-data-sheet.pdf |  | May apply on shipments to the U.S. |  | Active | ROHS3 Compliant | 1 (Unlimited) | EAR99 | 8536.10.0040 | China |  | 283-CB61F30A-TR1CT-ND | https://mm.digikey.com/Volume0/opasdata/d220001/medias/images/4330/MFG_CB61F20A-TR1.jpg
2 | 01220083Z | Littelfuse Inc. | FUSE CLIP CARTRIDGE 250V 30A PCB |  | 13,957 | In Stock |  | F3782-ND | 8 | https://www.littelfuse.com/assetdocs/littelfuse_fuse_clip_102_122_datasheet.pdf.pdf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 |  | May apply on shipments to the U.S. |  | Active | ROHS3 Compliant | Not Applicable | EAR99 | 8538.90.8180 | China | https://www.littelfusebusinesscenter.com/LFWeb/rohs_upload/RoHS_Certificate_of_Compliance/CoC_RoHS10_01220083Z_06-03-2019.pdf | F3782-ND | https://mm.digikey.com/Volume0/opasdata/d220001/medias/images/986/01220083Z.JPG
1 | 282828-2 | TE Connectivity AMP Connectors | TERM BLOCK HDR 2POS 10.16MM |  | 0 | Normally Stocking |  | A113312-ND | 10 | https://www.te.com/usa-en/product-282828-2.datasheet.pdf |  | N/A |  | Active | ROHS3 Compliant | 1 (Unlimited) | EAR99 | 8536.69.4040 | Italy | http://www.te.com/commerce/alt/SinglePartSearch.do?PN=282828-2&dest=stmt | A113312-ND | https://mm.digikey.com/Volume0/opasdata/d220001/medias/images/1131/282828-2.jpg
1 | 282809-2 | TE Connectivity AMP Connectors | TERM BLOCK PLUG 2POS 10.16MM |  | 5,739 | In Stock |  | A113288-ND | 12 | https://www.te.com/usa-en/product-282809-2.datasheet.pdf |  | N/A |  | Active | ROHS3 Compliant | 1 (Unlimited) | EAR99 | 8536.90.4000 | Italy | http://www.te.com/commerce/alt/SinglePartSearch.do?PN=282809-2&dest=stmt | A113288-ND | https://mm.digikey.com/Volume0/opasdata/d220001/medias/images/813/282809-2.jpg
1 | 0436500215 | Molex | CONN HEADER VERT 2POS 3MM |  | 55,468 | In Stock |  | WM1917-ND | 17 | https://www.molex.com/pdm_docs/sd/436500215_sd.pdf |  | N/A |  | Active | ROHS3 Compliant | 1 (Unlimited) | EAR99 | 8536.69.4040 | Mexico | https://www.molex.com/datasheets/rohspdf/0436500215_rohs.pdf | WM1917-ND | https://mm.digikey.com/Volume0/opasdata/d220001/medias/images/896/0436500215.jpg
1 | 0436450200 | Molex | CONN RCPT HSG 2POS 3.00MM |  | 120,584 | In Stock |  | WM1845-ND | 14 | https://www.molex.com/pdm_docs/sd/436450200_sd.pdf |  | N/A |  | Active | ROHS3 Compliant | 1 (Unlimited) | EAR99 | 8536.69.8000 | India | https://www.molex.com/datasheets/rohspdf/0436450200_rohs.pdf | WM1845-ND | https://mm.digikey.com/Volume0/opasdata/d220001/medias/images/813/43645-0200.jpg
1 | ASPI-4030S-4R7M-T | Abracon LLC | FIXED IND 4.7UH 2A 60 MOHM SMD |  | 25,494 | In Stock |  | 535-12322-1-ND | 10 | https://www.waldom.com/upload/parts/datasheets/mf-abr/abr-aspi-4030s-4r7m-t.pdf |  | May apply on shipments to the U.S. |  | Active | ROHS3 Compliant | 1 (Unlimited) | EAR99 | 8504.50.8000 | China | https://abracon.com/uploads/resources/REACH-224-SVHC-Certificate-Rev-S-2022-06-17-ABRACON-LLC.pdf | 535-12322-1-ND | https://mm.digikey.com/Volume0/opasdata/d220001/medias/images/500/ASPI-4030S-SERIES.jpg
1 | ASPI-4030S-100M-T | Abracon LLC | FIXED IND 10UH 1.5A 100 MOHM SMD |  | 35,148 | In Stock |  | 535-12314-1-ND | 10 | https://www.waldom.com/upload/parts/datasheets/mf-abr/aspi-4030s.pdf |  | May apply on shipments to the U.S. |  | Active | ROHS3 Compliant | 1 (Unlimited) | EAR99 | 8504.50.8000 | China | https://abracon.com/uploads/resources/REACH-224-SVHC-Certificate-Rev-S-2022-06-17-ABRACON-LLC.pdf | 535-12314-1-ND | https://mm.digikey.com/Volume0/opasdata/d220001/medias/images/500/ASPI-4030S-SERIES.jpg
1 | SIHP24N80AE-GE3 | Vishay Siliconix | MOSFET N-CH 800V 21A TO220AB |  | 930 | In Stock |  | 742-SIHP24N80AE-GE3-ND | 25 | https://www.vishay.com/docs/92296/sihp24n80ae.pdf |  | May apply on shipments to the U.S. |  | Active | ROHS3 Compliant | 1 (Unlimited) | EAR99 | 8541.29.0095 | China |  | 742-SIHP24N80AE-GE3-ND | https://mm.digikey.com/Volume0/opasdata/d220001/derivates/6/003/212/995/742%7E6031%7E%7E3_web%28640x640%29.jpg
5 | PMV20ENR | Nexperia USA Inc. | MOSFET N-CH 30V 6A TO236AB |  | 78,444 | In Stock |  | 1727-2301-1-ND | 16 | https://assets.nexperia.com/documents/data-sheet/PMV20EN.pdf |  | May apply on shipments to the U.S. |  | Active | ROHS3 Compliant | 1 (Unlimited) | EAR99 | 8541.29.0095 | China |  | 1727-2301-1-ND | https://mm.digikey.com/Volume0/opasdata/d220001/medias/images/6161/1727%7ESOT23-3%7E%7E3.jpg | No Backorders Allowed.
2 | IMBG65R050M2HXTMA1 | Infineon Technologies | SILICON CARBIDE MOSFET |  | 1,430 | In Stock |  | 448-IMBG65R050M2HXTMA1CT-ND | 23 | https://www.infineon.com/assets/row/public/documents/24/49/infineon-imbg65r050m2h-datasheet-en.pdf |  | N/A |  | Active | ROHS3 Compliant | 1 (Unlimited) | EAR99 | 8541.29.0095 | Austria |  | 448-IMBG65R050M2HXTMA1CT-ND | https://mm.digikey.com/Volume0/opasdata/d220001/medias/images/6167/448%7EPPG-TO263-7-12%7E%7E7.jpg
2 | BSC027N06LS5ATMA1 | Infineon Technologies | MOSFET N-CH 60V 100A TDSON |  | 83,172 | In Stock |  | BSC027N06LS5ATMA1CT-ND | 26 | https://www.infineon.com/dgdl/Infineon-BSC027N06LS5-DS-v02_00-EN.pdf?fileId=5546d46258fc0bc101596e1c881234d6 |  | N/A |  | Active | ROHS3 Compliant | 1 (Unlimited) | EAR99 | 8541.29.0095 | Germany | https://www.cypress.com/file/199231/download | BSC027N06LS5ATMA1CT-ND | https://mm.digikey.com/Volume0/opasdata/d220001/medias/images/4850/448_8-PowerTDFN.jpg
1 | ERJ-P08J470V | Panasonic Electronic Components | RES SMD 47 OHM 5% 2/3W 1206 |  | 48,765 | In Stock |  | P47ALCT-ND | 12 | https://industrial.panasonic.com/cdbs/www-data/pdf/RDO0000/AOA0000C331.pdf |  | N/A |  | Active | ROHS3 Compliant | 1 (Unlimited) | EAR99 | 8533.21.0030 | Japan | https://industrial.panasonic.com/cdbs/www-cgi/auto-publishing.cgi?type=ROSU&region=WW&layer=4&cd=AOA0002 | P47ALCT-ND | https://mm.digikey.com/Volume0/opasdata/d220001/medias/images/2384/ERJ-1206%20Pkg.jpg
1 | AC0603FR-07240KL | YAGEO | RES SMD 240K OHM 1% 1/10W 0603 |  | 1,627 | In Stock |  | 13-AC0603FR-07240KLCT-ND | 18 | https://www.yageogroup.com/content/datasheet/asset/file/PYU-AC_51_ROHS_L |  | N/A |  | Active | ROHS3 Compliant | 1 (Unlimited) | EAR99 | 8533.21.0030 | Taiwan |  | 13-AC0603FR-07240KLCT-ND | https://mm.digikey.com/Volume0/opasdata/d220001/medias/images/4205/AC-Series--SMD-Chip-Resistor.jpg
1 | AC0603JR-07330KL | YAGEO | RES SMD 330K OHM 5% 1/10W 0603 |  | 4,670 | In Stock |  | YAG3663CT-ND | 18 | https://www.yageogroup.com/content/datasheet/asset/file/PYU-AC_51_ROHS_L |  | N/A |  | Active | ROHS3 Compliant | 1 (Unlimited) | EAR99 | 8533.21.0030 | Taiwan |  | YAG3663CT-ND | https://mm.digikey.com/Volume0/opasdata/d220001/medias/images/4205/AC-Series--SMD-Chip-Resistor.jpg
1 | RC0603FR-0747KL | YAGEO | RES 47K OHM 1% 1/10W 0603 |  | 3,781,031 | In Stock |  | 311-47.0KHRCT-ND | 18 | https://www.yageogroup.com/content/datasheet/asset/file/PYU-RC_GROUP_51_ROHS_L |  | N/A |  | Active | ROHS3 Compliant | 1 (Unlimited) | EAR99 | 8533.21.0030 | Taiwan | https://www.yageogroup.com/content/Resource%20Library/Product%20Environmental%20Compliance/RoHS_Compliance_YAGEO.pdf | 311-47.0KHRCT-ND | https://mm.digikey.com/Volume0/opasdata/d220001/medias/images/4322/cut-tape-render.jpg
1 | CRCW0603510RFKEAC | Vishay Dale | RES 510 OHM 1% 1/10W 0603 |  | 101,287 | In Stock |  | 541-5462-1-ND | 18 | https://www.vishay.com/docs/28773/crcwce3.pdf |  | May apply on shipments to the U.S. |  | Active | ROHS3 Compliant | 1 (Unlimited) | EAR99 | 8533.21.0030 | China |  | 541-5462-1-ND | https://mm.digikey.com/Volume0/opasdata/d220001/medias/images/2491/CRCW%200603%20%281608metric%29.jpg
1 | CR1206-FX-20R0ELF | Bourns Inc. | RES SMD 20 OHM 1% 1/4W 1206 |  | 7,292 | In Stock |  | CR1206-FX-20R0ELFCT-ND | 12 | https://bourns.com/docs/product-datasheets/cr.pdf?sfvrsn=574d41f6_14 |  | N/A |  | Active | ROHS3 Compliant | 1 (Unlimited) | EAR99 | 8533.21.0030 | Taiwan | https://www.bourns.com/docs/Product-MDS/cr1206_mds.pdf|https://mm.digikey.com/Volume0/opasdata/d220001/medias/docus/6657/Bourns%20REACH%20247%20Jan%202025%20Statement.pdf|https://www.bourns.com/docs/rohs-cofc/crx_coc.pdf?sfvrsn=db3a74f6_10 | CR1206-FX-20R0ELFCT-ND | https://mm.digikey.com/Volume0/opasdata/d220001/derivates/6/200/269/248/CR1206-%283216-Metric%29_web%28640x640%29.jpg
1 | CHV1206-JW-106ELF | Bourns Inc. | RES SMD 10M OHM 5% 1/4W 1206 |  | 99,217 | In Stock |  | CHV1206-JW-106ELFCT-ND | 14 | https://www.bourns.com/docs/product-datasheets/chv.pdf |  | N/A |  | Active | ROHS3 Compliant | 1 (Unlimited) | EAR99 | 8533.21.0030 | Taiwan | https://www.bourns.com/docs/rohs-cofc/ca.pdf?sfvrsn=c71494f1_4|https://mm.digikey.com/Volume0/opasdata/d220001/medias/docus/6657/Bourns%20REACH%20247%20Jan%202025%20Statement.pdf|https://www.bourns.com/docs/rohs-cofc/chp_chv_cofc.pdf?sfvrsn=6cd47df6_12 | CHV1206-JW-106ELFCT-ND | https://mm.digikey.com/Volume0/opasdata/d220001/medias/images/15/1206%283216_Metric%29.jpg
1 | RC0603JR-0782KL | YAGEO | RES 82K OHM 5% 1/10W 0603 |  | 423,277 | In Stock |  | 311-82KGRCT-ND | 18 | https://www.yageogroup.com/content/datasheet/asset/file/PYU-RC_GROUP_51_ROHS_L |  | N/A |  | Active | ROHS3 Compliant | 1 (Unlimited) | EAR99 | 8533.21.0030 | Taiwan | https://www.yageogroup.com/content/Resource%20Library/Product%20Environmental%20Compliance/RoHS_Compliance_YAGEO.pdf | 311-82KGRCT-ND | https://mm.digikey.com/Volume0/opasdata/d220001/medias/images/4848/13_0603-%281608-metric%29.jpg
1 | CR0603-FX-8203ELF | Bourns Inc. | RES SMD 820K OHM 1% 1/10W 0603 |  | 23,684 | In Stock |  | CR0603-FX-8203ELFCT-ND | 12 | https://bourns.com/docs/product-datasheets/cr.pdf?sfvrsn=574d41f6_14 |  | N/A |  | Active | ROHS3 Compliant | 1 (Unlimited) | EAR99 | 8533.21.0030 | Taiwan | https://www.bourns.com/docs/Product-MDS/cr0603_mds.pdf|https://mm.digikey.com/Volume0/opasdata/d220001/medias/docus/6657/Bourns%20REACH%20247%20Jan%202025%20Statement.pdf|https://www.bourns.com/docs/rohs-cofc/crx_coc.pdf?sfvrsn=db3a74f6_10 | CR0603-FX-8203ELFCT-ND | https://mm.digikey.com/Volume0/opasdata/d220001/medias/images/505/CR0603-%281608-Metric%29.jpg
1 | CR0603-JW-514ELF | Bourns Inc. | RES SMD 510K OHM 5% 1/10W 0603 |  | 51,260 | In Stock |  | CR0603-JW-514ELFCT-ND | 12 | https://bourns.com/docs/product-datasheets/cr.pdf?sfvrsn=574d41f6_14 |  | N/A |  | Active | ROHS3 Compliant | 1 (Unlimited) | EAR99 | 8533.21.0030 | Taiwan | https://www.bourns.com/docs/Product-MDS/cr0603_mds.pdf|https://mm.digikey.com/Volume0/opasdata/d220001/medias/docus/6657/Bourns%20REACH%20247%20Jan%202025%20Statement.pdf|https://www.bourns.com/docs/rohs-cofc/crx_coc.pdf?sfvrsn=db3a74f6_10 | CR0603-JW-514ELFCT-ND | https://mm.digikey.com/Volume0/opasdata/d220001/medias/images/505/CR0603-%281608-Metric%29.jpg
1 | AC0603FR-071M6L | YAGEO | RES SMD 1.6M OHM 1% 1/10W 0603 |  | 5,556 | In Stock |  | 13-AC0603FR-071M6LCT-ND | 18 | https://www.yageogroup.com/content/datasheet/asset/file/PYU-AC_51_ROHS_L |  | N/A |  | Active | ROHS3 Compliant | 1 (Unlimited) | EAR99 | 8533.21.0030 | Taiwan |  | 13-AC0603FR-071M6LCT-ND | https://mm.digikey.com/Volume0/opasdata/d220001/medias/images/4205/AC-Series--SMD-Chip-Resistor.jpg
6 | ESR03EZPJ104 | Rohm Semiconductor | RES 100K OHM 5% 1/4W 0603 |  | 25,486 | In Stock |  | RHM100KDCT-ND | 13 | https://fscdn.rohm.com/en/products/databook/datasheet/passive/resistor/chip_resistor/esr-e.pdf |  | N/A |  | Active | ROHS3 Compliant | 1 (Unlimited) | EAR99 | 8533.21.0030 | Philippines |  | RHM100KDCT-ND | https://mm.digikey.com/Volume0/opasdata/d220001/medias/images/5652/511_ESR01.jpg
2 | CHV2512-JW-107ELF | Bourns Inc. | RES SMD 100M OHM 5% 1W 2512 |  | 35,427 | In Stock |  | CHV2512-JW-107ELFCT-ND | 18 | https://www.bourns.com/docs/product-datasheets/chv.pdf |  | N/A |  | Active | ROHS3 Compliant | 1 (Unlimited) | EAR99 | 8533.21.0030 | Taiwan | https://www.bourns.com/docs/rohs-cofc/ca.pdf?sfvrsn=c71494f1_4|https://mm.digikey.com/Volume0/opasdata/d220001/medias/docus/6657/Bourns%20REACH%20247%20Jan%202025%20Statement.pdf|https://www.bourns.com/docs/rohs-cofc/chp_chv_cofc.pdf?sfvrsn=6cd47df6_12 | CHV2512-JW-107ELFCT-ND | https://mm.digikey.com/Volume0/opasdata/d220001/derivates/6/010/207/762/CRA2512_web%28640x640%29.jpg
2 | RC1206JR-7W100RL | YAGEO | RES 100 OHM 5% 1/2W 1206 |  | 5,257 | In Stock |  | 13-RC1206JR-7W100RLCT-ND | 18 | https://www.yageogroup.com/content/datasheet/asset/file/PYU-RC_GROUP_51_ROHS_L |  | N/A |  | Active | ROHS3 Compliant | 1 (Unlimited) | EAR99 | 8533.21.0030 | Taiwan | https://www.yageogroup.com/content/Resource%20Library/Product%20Environmental%20Compliance/RoHS_Compliance_YAGEO.pdf | 13-RC1206JR-7W100RLCT-ND | https://mm.digikey.com/Volume0/opasdata/d220001/medias/images/4842/Yageo-0603.jpg
1 | CR0603-JW-273ELF | Bourns Inc. | RES SMD 27K OHM 5% 1/10W 0603 |  | 17,642 | In Stock |  | CR0603-JW-273ELFCT-ND | 12 | https://bourns.com/docs/product-datasheets/cr.pdf?sfvrsn=574d41f6_14 |  | N/A |  | Active | ROHS3 Compliant | 1 (Unlimited) | EAR99 | 8533.21.0030 | Taiwan | https://www.bourns.com/docs/Product-MDS/cr0603_mds.pdf|https://mm.digikey.com/Volume0/opasdata/d220001/medias/docus/6657/Bourns%20REACH%20247%20Jan%202025%20Statement.pdf|https://www.bourns.com/docs/rohs-cofc/crx_coc.pdf?sfvrsn=db3a74f6_10 | CR0603-JW-273ELFCT-ND | https://mm.digikey.com/Volume0/opasdata/d220001/medias/images/505/CR0603-%281608-Metric%29.jpg
1 | MCT06030C1802FP500 | Vishay | RES 18K OHM 1% 1/10W 0603 |  | 25,942 | In Stock |  | MCT0603-18.0K-CFCT-ND | 12 | https://www.vishay.com/docs/28700/mcx0x0xpre.pdf |  | N/A |  | Active | ROHS3 Compliant | 1 (Unlimited) | EAR99 | 8533.21.0030 | Israel |  | MCT0603-18.0K-CFCT-ND | https://mm.digikey.com/Volume0/opasdata/d220001/medias/images/2926/MCT%200603.jpg
3 | CRCW0603470KJNEAHP | Vishay Dale | RES SMD 470K OHM 5% 1/3W 0603 |  | 17,222 | In Stock |  | 541-470KSACT-ND | 14 | https://www.vishay.com/docs/20043/crcwhpe3.pdf |  | N/A |  | Active | ROHS3 Compliant | 1 (Unlimited) | EAR99 | 8533.21.0030 | Israel |  | 541-470KSACT-ND | https://mm.digikey.com/Volume0/opasdata/d220001/medias/images/57/MFG_CRCW-HP_e3_Series.jpg
2 | ERJ-P06J334V | Panasonic Electronic Components | RES SMD 330K OHM 5% 1/2W 0805 |  | 68,486 | In Stock |  | P330KADCT-ND | 12 | https://industrial.panasonic.com/cdbs/www-data/pdf/RDO0000/AOA0000C331.pdf |  | N/A |  | Active | ROHS3 Compliant | 1 (Unlimited) | EAR99 | 8533.21.0030 | Japan | https://industrial.panasonic.com/cdbs/www-cgi/auto-publishing.cgi?type=ROSU&region=WW&layer=4&cd=AOA0002 | P330KADCT-ND | https://mm.digikey.com/Volume0/opasdata/d220001/medias/images/2502/ERJ-0805%20Pkg.jpg
3 | AC0603FR-0733KL | YAGEO | RES SMD 33K OHM 1% 1/10W 0603 |  | 68 | In Stock |  | YAG3598CT-ND | 18 | https://www.yageogroup.com/content/datasheet/asset/file/PYU-AC_51_ROHS_L |  | N/A |  | Active | ROHS3 Compliant | 1 (Unlimited) | EAR99 | 8533.21.0030 | Taiwan |  | YAG3598CT-ND | https://mm.digikey.com/Volume0/opasdata/d220001/medias/images/4205/AC-Series--SMD-Chip-Resistor.jpg
3 | CRCW06034K70FKEC | Vishay Dale | RES SMD 4.7K OHM 1% 1/8W 0603 |  | 63,291 | In Stock |  | 541-CRCW06034K70FKECCT-ND | 13 | https://www.vishay.com/docs/20035/dcrcwe3.pdf |  | May apply on shipments to the U.S. |  | Active | ROHS3 Compliant | 1 (Unlimited) | EAR99 | 8533.21.0030 | China |  | 541-CRCW06034K70FKECCT-ND | https://mm.digikey.com/Volume0/opasdata/d220001/medias/images/2491/CRCW%200603%20%281608metric%29.jpg
2 | ERJ-P08J4R7V | Panasonic Electronic Components | RES SMD 4.7 OHM 5% 2/3W 1206 |  | 8,645 | In Stock |  | 10-ERJ-P08J4R7VCT-ND | 12 | https://industrial.panasonic.com/cdbs/www-data/pdf/RDO0000/AOA0000C331.pdf |  | N/A |  | Active | ROHS3 Compliant | 1 (Unlimited) | EAR99 | 8533.21.0030 | Japan | https://industrial.panasonic.com/cdbs/www-cgi/auto-publishing.cgi?type=ROSU&region=WW&layer=4&cd=AOA0002 | 10-ERJ-P08J4R7VCT-ND | https://mm.digikey.com/Volume0/opasdata/d220001/medias/images/2384/ERJ-1206%20Pkg.jpg
2 | ESR03EZPJ102 | Rohm Semiconductor | RES 1K OHM 5% 1/4W 0603 |  | 20,887 | In Stock |  | 846-ESR03EZPJ102CT-ND | 13 | https://fscdn.rohm.com/en/products/databook/datasheet/passive/resistor/chip_resistor/esr-e.pdf |  | N/A |  | Active | ROHS3 Compliant | 1 (Unlimited) | EAR99 | 8533.21.0030 | Philippines |  | 846-ESR03EZPJ102CT-ND | https://mm.digikey.com/Volume0/opasdata/d220001/medias/images/4322/cut-tape-render.jpg
17 | ESR03EZPJ103 | Rohm Semiconductor | RES 10K OHM 5% 1/4W 0603 |  | 118,659 | In Stock |  | RHM10KDCT-ND | 13 | https://fscdn.rohm.com/en/products/databook/datasheet/passive/resistor/chip_resistor/esr-e.pdf |  | N/A |  | Active | ROHS3 Compliant | 1 (Unlimited) | EAR99 | 8533.21.0030 | Philippines |  | RHM10KDCT-ND | https://mm.digikey.com/Volume0/opasdata/d220001/medias/images/4322/cut-tape-render.jpg
2 | RC1206FR-7W10RL | YAGEO | RES 10 OHM 1% 1/2W 1206 |  | 15,829 | In Stock |  | 13-RC1206FR-7W10RLCT-ND | 18 | https://www.yageogroup.com/content/datasheet/asset/file/PYU-RC_GROUP_51_ROHS_L |  | N/A |  | Active | ROHS3 Compliant | 1 (Unlimited) | EAR99 | 8533.21.0030 | Taiwan | https://www.yageogroup.com/content/Resource%20Library/Product%20Environmental%20Compliance/RoHS_Compliance_YAGEO.pdf | 13-RC1206FR-7W10RLCT-ND | https://mm.digikey.com/Volume0/opasdata/d220001/medias/images/4842/Yageo-0603.jpg
2 | CRCW0603100MJPEAHR | Vishay Dale | RES SMD 100M OHM 5% 1/8W 0603 |  | 265,533 | In Stock |  | 541-100MAHCT-ND | 14 | https://www.vishay.com/docs/20022/dcrcwhre3.pdf |  | N/A |  | Active | ROHS3 Compliant | 1 (Unlimited) | EAR99 | 8533.21.0030 | Israel |  | 541-100MAHCT-ND | https://mm.digikey.com/Volume0/opasdata/d220001/medias/images/2491/CRCW%200603%20%281608metric%29.jpg
2 | ERJ-PA3J100V | Panasonic Electronic Components | RES SMD 10 OHM 5% 1/3W 0603 |  | 126,699 | In Stock |  | P10.00BZCT-ND | 12 | https://industrial.panasonic.com/cdbs/www-data/pdf/RDO0000/AOA0000C331.pdf |  | N/A |  | Active | ROHS3 Compliant | 1 (Unlimited) | EAR99 | 8533.21.0030 | Japan | https://industrial.panasonic.com/cdbs/www-cgi/auto-publishing.cgi?type=ROSU&region=WW&layer=4&cd=AOA0002 | P10.00BZCT-ND | https://mm.digikey.com/Volume0/opasdata/d220001/medias/images/2606/MFG_ERJ-P6W%20Series.jpg
8 | ESR03EZPJ222 | Rohm Semiconductor | RES 2.2K OHM 5% 1/4W 0603 |  | 239,441 | In Stock |  | RHM2.2KDCT-ND | 13 | https://fscdn.rohm.com/en/products/databook/datasheet/passive/resistor/chip_resistor/esr-e.pdf |  | N/A |  | Active | ROHS3 Compliant | 1 (Unlimited) | EAR99 | 8533.21.0030 | Philippines |  | RHM2.2KDCT-ND | https://mm.digikey.com/Volume0/opasdata/d220001/medias/images/5652/511_ESR01.jpg
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

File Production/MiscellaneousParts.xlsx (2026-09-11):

Component | Name | Quantity/Length | Link | Notes | Cost
Fan |  | 1 | https://www.amazon.com/Dorhea-Raspberry-30x30x7mm-Brushless-Cooling/dp/B07G97L9TL |  | $5.99
Heatsink for Q8 Q9 | 6x6x3mm | 1 | https://www.amazon.com/MECCANIXITY-Heatsink-6x6x5mm-Adhesive-Chipset/dp/B0B7F461N2 |  | $5.93
solder paste and flux |  | 1 | https://www.amazon.com/Solder-Paste-Lead-Free-Supplied-Wonderway/dp/B0D1C7QH76 |  | $11.99
Heat Shrink |  | 1 | www.amazon.com/Ginsco-580-pcs-Assorted-Sleeving/dp/B01MFA3OFA |  | $6.99
 |  |  |  |  | $30.90
Connection Cable | For LV (may not need) | 1 | https://www.amazon.com/Electrical-Silicone-Flexible-temperature-resistance/dp/B0756TDTDM |  | $11.98
Connection Cable | for TH1 | 1 | https://www.amazon.com/Electrical-Gauge-Silicone-Cable-Black/dp/B0746HG158 |  | $5.18
Conformal Coating | Meets FSAE Standards | 1 | https://www.digikey.com/en/products/detail/mg-chemicals/422C-55MLCA/11617902 |  | $29.28

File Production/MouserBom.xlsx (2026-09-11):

Mfr Part Number (Input) | Quantity 1 | Mfr Part Number | Mouser Part Number | Manufacturer Name | Description | Unit Price 1 | Order Quantity | Order Unit Price | Min./Mult. | Availability | Lead Time in Days | Lead Time in Weeks | Lifecycle | NCNR | RoHS | Pb Free | Package Type | Package Quantity | Datasheet URL | Product Image | Design Risk | Estimated Tariff Price | Estimated Tariff Ext.
75-MKP1848520704K2 | 1 | MKP1848520704K2 | 75-MKP1848520704K2 | Vishay | Film Capacitors Film Capacitors 2uF 700volt 5% 2pin 27.5mm LS | $1.58 | 1 | $1.58 | 1\1 | 6,784 | 98 | 14 |  | No | Yes | Yes | TRAY | 160 | https://www.vishay.com/doc?28164 |  | Product has high popularity and is readily available.
187-CL21B225KBYNNWE | 3 | CL21B225KBYNNWE | 187-CL21B225KBYNNWE | Samsung Electro-Mechanics | Multilayer Ceramic Capacitors MLCC - SMD/SMT Multilayer Ceramic Capacitors MLCC - SMD/SMT 2.2uF X7R +/-10% 50v 0805 | $0.24 | 1 | $0.24 | 1\1 | 106,794 | 140 | 20 |  | No | Yes | Yes | REEL | 2,000 | https://www.mouser.com/catalog/specsheets/Samsung_MLCC-1837944.pdf |  | Product has high popularity and is readily available. | $0.036 | $0.04
963-MSAST32MAB5476MP | 5 | MSAST32MAB5476MPNDT1 | 963-MSAST32MAB5476MP | TAIYO YUDEN | Multilayer Ceramic Capacitors MLCC - SMD/SMT Multilayer Ceramic Capacitors MLCC - SMD/SMT 25V 47uF X5R 1210 20% | $1.26 | 1 | $1.26 | 1\1 | 25,944 | 119 | 17 |  | No | Yes | Yes | REEL | 1,000 | https://www.mouser.com/catalog/specsheets/Tayio_Yuden_1102023_MS_mlcc_all_e.pdf |  | Product has high popularity and is readily available. | $0.17 | $0.17
791-SH31B102K631CT | 2 | SH31B102K631CT | 791-SH31B102K631CT | Walsin | Multilayer Ceramic Capacitors MLCC - SMD/SMT Multilayer Ceramic Capacitors MLCC - SMD/SMT 630V 1000 pF 10% X7R - 55 C + 125 C 1206 Flex Term | $0.11 | 1 | $0.11 | 1\1 | 9,518 | 107 | 16 |  | No | Yes | Yes | REEL | 3,000 | https://www.mouser.com/datasheet/3/317/1/WTC_MLCC_Soft_term_SH.pdf |  | Product has high popularity and is readily available.
743-IN-S63AT5G | 5 | IN-S63AT5G | 743-IN-S63AT5G | Inolux | Single Color LEDs Single Color LEDs True Green LED | $0.25 | 1 | $0.25 | 1\1 | 5,218 | 35 | 5 |  | No | Yes | Yes | REEL | 4,000 | https://www.mouser.com/datasheet/3/760/1/IN-S63AT Series_V1.1.pdf |  | Product has high popularity and is readily available. | $0.075 | $0.08
571-284051-2 | 1 | 284051-2 | 571-284051-2 | TE Connectivity | Pluggable Terminal Blocks Pluggable Terminal Blocks TERMI-BLOK VERTICAL PLUG STACK | $1.45 | 1 | $1.45 | 1\1 | 1,597 | 65 | 10 |  | No | Yes | No | BULK | 200 | https://www.te.com/commerce/DocumentDelivery/DDEController?Action=srchrtrv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 |  | Product has high popularity and is readily available. | $0.145 | $0.15
538-42375-2486 | 5 | 42375-2486 | 538-42375-2486 | Molex | Headers & Wire Housings Headers & Wire Housings KK 100 Hdr Assy Bkw 02 Ckt 15 SGold | $0.15 | 1 | $0.15 | 1\1 | 27,273 |  |  |  | No | Yes | No |  | 30,000 | https://tools.molex.com/pdm_docs/sd/423752486_sd.pdf |  | Product has high popularity and is readily available.
538-35044-9102 | 2 | 35044-9102 | 538-35044-9102 | Molex | Headers & Wire Housings Headers & Wire Housings TERMINAL FOR 2.0/2.5 R 2.0/2.5 B-IN CONN. | $0.10 | 1 | $0.10 | 1\1 | 57,691 | 84 | 12 |  | No | Yes | No |  | 96,000 | https://www.molex.com/en-us/products/part-detail-pdf/350449102?display=pdf |  | Product has high popularity and is readily available.
710-7443091080 | 1 | 7443091080 | 710-7443091080 | Wurth Elektronik | Power Inductors - SMD Power Inductors - SMD WE-HCM SMT HighCurr 0.8uH 34A 0.42mOhms | $3.01 | 1 | $3.01 | 1\1 | 366 | 44 | 7 |  | No | Yes | Yes | REEL | 250 | https://www.we-online.com/components/products/datasheet/7443091080.pdf |  | Product has moderate popularity and is readily available. | $1.19 | $1.19
747-IXYP8N90C3 | 1 | IXYP8N90C3 | 747-IXYP8N90C3 | IXYS | IGBTs IGBTs XPT 900V IGBT GenX3 XPT IGBT | $3.56 | 1 | $3.56 | 1\1 | 233 | 259 | 37 |  | No | Yes | No | TUBE | 50 | https://www.mouser.com/datasheet/3/100/1/Littelfuse_Discrete_IGBTs_XPT_IXY_8N90C3_Datasheet.PDF |  | Product has high popularity and is readily available.
835-RT9058-90GVL | 1 | RT9058-90GVL | 835-RT9058-90GVL | Richtek | LDO Voltage Regulators LDO Voltage Regulators 36V, 2 A IQ, 100mA Low Dropout Voltage Linear Regulator | $1.36 | 1 | $1.36 | 1\1 | 2,150 |  |  |  | No | Yes | Yes | REEL | 3,000 | https://www.richtek.com/SaveDownload.aspx?specid=RT9058 |  | Product has high popularity and is readily available.
595-TL431BCDBZR | 1 | TL431BCDBZR | 595-TL431BCDBZR | Texas Instruments | Voltage References Voltage References Adjustable Precision Shunt Regulator A 595-TL431BCDBZT | $0.34 | 1 | $0.34 | 1\1 | 1,832 | 42 | 6 |  | No | Yes | No | REEL | 3,000 | https://www.ti.com/lit/gpn/tl431c |  | Product has high popularity and is readily available. | $0.19 | $0.19
630-ACPL-217-560E | 1 | ACPL-217-560E | 630-ACPL-217-560E | Broadcom Limited | Transistor Output Optocouplers Transistor Output Optocouplers 3000Vrms 50% CTR | $0.71 | 1 | $0.71 | 1\1 | 30,113 | 140 | 20 |  | No | Yes | Yes | REEL | 3,000 | https://www.mouser.com/datasheet/3/57/1/AV02_0470EN_2023_10_11.pdf |  | Product has high popularity and is readily available. | $0.398 | $0.40
595-UCC21520DW | 1 | UCC21520DW | 595-UCC21520DW | Texas Instruments | Galvanically Isolated Gate Drivers Galvanically Isolated Gate Drivers 5.7kVrms 4A/6A dual -channel isolated ga A 595-UCC21520DWR | $8.11 | 1 | $8.11 | 1\1 | 2,887 |  |  | End of Life | Yes | Yes | Yes | TUBE | 40 | https://www.ti.com/lit/pdf/slua778a |  | Product is no longer being produced.

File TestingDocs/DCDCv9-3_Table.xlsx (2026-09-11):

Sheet: Notes
DCDCv9-3 Table
GitHub: https://github.com/Rootthecause/DCDC
Date: | 2025-05-20
Dear user! The author is not liable for any damages in connection with this document, nor does he guarantee the functionality or correctness of the formulas and measurements described. Use is at your own risk!
This document was created in Google Sheets. The design and functions may vary if a different application used is used.
Found an error? Please submit an Issue on GitHub. Thanks a lot! (https://github.com/Rootthecause/DCDC/issues)
Revision History
May 20, 2025 | Added Revision History, Added Cstart1 (Internenal Power Supply) storage time and voltage after this time
May 22, 2025 | Unified date format to DD.MM.YY , renamed 24V_in on the output side to 24V output, assigned 12.2V to the LV side, changed color from green to orange in the Measurements Table for optional measurements, fixed capacitor loss calculator (results where too high by a factor of 2)

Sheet: Checklist v9-3
 | Checklist DCDCv9-3 | Identifier for Oscilloscope Screenshots: C | Test passed | 199 | of | 199 | 100.00% | tests done
Essential | Module | Parameter | Value | Unit |  |  | Date | Status | Comment
x | Start-up Cap Supply | Charging Voltage (with C_start), DC/DC Disabled | 3.71 | V | min. 3,5 | max. 3,8 | 2024-10-31 | OK | Constant above 7 V_in (which is the Voltage on the output connector)
 | Start-up Cap Supply | Charging Voltage (with C_start), DC/DC Enabled, U_in = 600 V, IDLE, 5V Fan OFF | 3.69 | V | min. 3,5 | max. 3,8 | 2024-11-28 | OK
 | Start-up Cap Supply | Charging Voltage (with C_start), DC/DC Enabled, U_in = 600 V, IDLE, 5V Fan ON | 3.68 | V | min. 3,5 | max. 3,8 | 2024-11-28 | OK
 | Start-up Cap Supply | Capacitor Shipping Voltage | 3.65 | V | min. 3,5 | max. 3,8 | 2024-11-01 | OK
 | Start-up Cap Supply | Input current with fully charged capacitor, 24V output, Disabled | 1.05 | mA |  |  | 2024-11-01 | OK
x | Start-up Cap Supply | Input current with fully charged capacitor, 24V output, Enabled | 22.3 | mA |  |  | 2025-01-07 | OK
 | Start-up Cap Supply | Input current with fully charged capacitor, 24V output, Enabled, with 5V Fan, 21°C RT | 50 | mA |  |  | 2025-01-07 | OK
x | Start-up Cap Supply | Discharge Current (DC/DC Enabled) no HV, Cap @ 3,70 V | 101 | mA |  |  | 2024-11-01 | OK
 | Start-up Cap Supply | Discharge Current (DC/DC Enabled) 200 V | 198 | mA |  |  | 2024-11-27 | OK
 | Start-up Cap Supply | Discharge Current (DC/DC Enabled) 300 V | 207 | mA |  |  | 2024-11-27 | OK
 | Start-up Cap Supply | Discharge Current (DC/DC Enabled) 400 V | 219 | mA |  |  | 2024-11-27 | OK
 | Start-up Cap Supply | Discharge Current (DC/DC Enabled) 500 V | 236 | mA |  |  | 2024-11-27 | OK
x | Start-up Cap Supply | Discharge Current (DC/DC Enabled) 600 V | 215 | mA |  |  | 2024-11-27 | OK
x | Start-up Cap Supply | Hold-Up time, DC/DC Enabled, no HV | 114 | s |  |  | 2024-11-01 | OK
 | Start-up Cap Supply | Hold-Up time, DC/DC Disbaled | > 6 | months |  |  | 2025-05-20 | OK | after 6 Months of not in use ~20 mV reduction, probably fine for >12 Months.
 | Start-up Cap Supply | Voltage after 6 months, DC/DC Disbaled | 3.676 | V |  |  | 2025-05-20 | OK
 | Start-up Cap Supply | 5V LED / step-down turn off input voltage | 3.5 | V |  |  | 2024-11-01 | OK
 | Start-up Cap Supply | 5V LED / step-down turn off time by discharging C11+C13 from 24V, no load, | 172 | s |  |  | 2024-11-01 | OK
 | Step-Up UVLO | must be above min. C_start voltage | 2.535 | V | min. 2,5 | max. 3 | 2024-10-31 | OK but improveable | without C_start: 2,45 V.
 | LV Voltage LV Side Current | U_in = 0 V / DC/DC Enabled, IDLE, 12.2 V LV | 27.8 | mA |  |  | 2025-01-07 | OK
x | LV Voltage LV Side Voltage | U_in = 0 V / DC/DC Enabled, IDLE | 12.204 | V |  |  | 2024-10-31 | OK
x | LV Voltage 9 V LDO | U_in = 0 V / DC/DC Enabled, IDLE, 12.2 V LV, 20,1°C RT | 9.055 | V |  |  | 2024-10-31 | OK
x | LV Voltage, HV Side | U_in = 0 V / DC/DC Enabled, IDLE, 12.2 V LV | 12.475 | V |  |  | 2024-10-31 | OK
x | LV Voltage, HV Side after D11 | U_in = 0 V / DC/DC Enabled, IDLE, 12.2 V LV | 11.79 | V |  |  | 2024-10-31 | OK
x | LV Voltage, HV Side after D14 | U_in = 0 V / DC/DC Enabled, IDLE, 12.2 V LV | 12.108 | V |  |  | 2024-10-31 | OK
 | MOSFET top supply Voltage (VDDA-VSSA) | U_in = 200 V / DC/DC Enabled, IDLE, Cap @ 3,75 V | 11.71 | V |  |  | 2024-11-28 | OK | WARNING: DO NOT MEASURE THIS WITHOUT EXTRA PRECAUTION! HV SWITCHNODE!
 | MOSFET top supply Voltage (VDDA-VSSA) | U_in = 300 V / DC/DC Enabled, IDLE, Cap @ 3,75 V | 11.82 | V |  |  | 2024-11-28 | OK | WARNING: DO NOT MEASURE THIS WITHOUT EXTRA PRECAUTION! HV SWITCHNODE!
 | MOSFET top supply Voltage (VDDA-VSSA) | U_in = 400 V / DC/DC Enabled, IDLE, Cap @ 3,75 V | 11.96 | V |  |  | 2024-11-28 | OK | WARNING: DO NOT MEASURE THIS WITHOUT EXTRA PRECAUTION! HV SWITCHNODE!
 | MOSFET top supply Voltage (VDDA-VSSA) | U_in = 500 V / DC/DC Enabled, IDLE, Cap @ 3,75 V | 11.40 | V |  |  | 2024-11-28 | OK | WARNING: DO NOT MEASURE THIS WITHOUT EXTRA PRECAUTION! HV SWITCHNODE!
 | MOSFET top supply Voltage (VDDA-VSSA) | U_in = 600 V / DC/DC Enabled, IDLE, Cap @ 3,75 V | 10.66 | V |  |  | 2024-11-28 | OK | WARNING: DO NOT MEASURE THIS WITHOUT EXTRA PRECAUTION! HV SWITCHNODE!
 | Precharge | Precharge Close delay | 5,0 ... 5,3 | ms |  |  | 2024-11-27 | OK | Only slightly dependent on U_in
 | Precharge | Precharge Close Voltage Jump | 9 | V |  |  | 2024-11-27 | OK | Hard to measure, simulation might be more accurate
 | Precharge | Precharge Open Delay | 7 | ms |  |  | 2024-11-28 | OK
 | Precharge | Mad-Scruti-Test (Enable/Disable DC/DC as mad as possible) | PASS |  |  |  | 2024-11-28 | OK
 | Precharge | Precharge Time 200 V to 60V, 21°C RT | 68 | ms |  |  | 2024-11-27 | OK
 | Precharge | Precharge Time 300 V to 60V, 21°C RT | 103 | ms |  |  | 2024-11-27 | OK
 | Precharge | Precharge Time 400 V to 60V, 21°C RT | 141 | ms |  |  | 2024-11-27 | OK
 | Precharge | Precharge Time 500 V to 60V, 21°C RT | 180 | ms |  |  | 2024-11-27 | OK
 | Precharge | Precharge Time 600 V to 60V, 21°C RT | 221 | ms |  |  | 2024-11-27 | OK
 | Passive Discharge | Discharge Time 200 V to 60V, 21°C RT | 1.592 | s |  |  | 2025-01-07 | OK
 | Passive Discharge | Discharge Time 300 V to 60V, 21°C RT | 2.120 | s |  |  | 2025-01-07 | OK
 | Passive Discharge | Discharge Time 400 V to 60V, 21°C RT | 2.540 | s |  |  | 2025-01-07 | OK
 | Passive Discharge | Discharge Time 500 V to 60V, 21°C RT | 2.795 | s |  |  | 2025-01-07 | OK
 | Passive Discharge | Discharge Time 600 V to 60V, 21°C RT | 3.045 | s |  |  | 2025-01-07 | OK
 | Leakage Current Turned off | 200 V, 21°C RT | 15 | nA |  |  | 2024-11-27 | OK | 13,3 GΩ
 | Leakage Current Turned off | 300 V, 21°C RT | 28 | nA |  |  | 2024-11-27 | OK | 10,7 GΩ
 | Leakage Current Turned off | 400 V, 21°C RT | 41 | nA |  |  | 2024-11-27 | OK | 9,8 GΩ
 | Leakage Current Turned off | 500 V, 21°C RT | 56 | nA |  |  | 2024-11-27 | OK | 8,9 GΩ
 | Leakage Current Turned off | 600 V, 21°C RT | 75 | nA |  |  | 2024-11-27 | OK | 8,0 GΩ
 | Input Current, Turned ON, below UVP | 50V, 21°C RT | 75 | µA |  |  | 2024-12-11 | OK
 | Input Current, Turned ON, below UVP | 100V, 21°C RT | 151 | µA |  |  | 2024-12-11 | OK
 | Input Current, Turned ON, below UVP | 150V, 21°C RT | 228 | µA |  |  | 2024-12-11 | OK
 | Input Current, Turned ON, below UVP | 200V, 21°C RT | 305 | µA |  |  | 2024-12-11 | OK
 | Input Current, Turned ON, above UVP | 200 V, 21°C RT, no Fan, dead time = 80° | 40.0 | mA | 8.00 | W | 2025-01-07 | OK
 | Input Current, Turned ON, above UVP | 300 V, 21°C RT, no Fan, dead time = 80° | 27.2 | mA | 8.16 | W | 2025-01-07 | OK
x | Input Current, Turned ON, above UVP | 400 V, 21°C RT, no Fan, dead time = 80° | 20.8 | mA | 8.32 | W | 2025-01-07 | OK
x | Input Current, Turned ON, above UVP | 500 V, 21°C RT, no Fan, dead time = 80° | 16.7 | mA | 8.33 | W | 2025-01-07 | OK
x | Input Current, Turned ON, above UVP | 600 V, 21°C RT, no Fan, dead time = 80° | 11.34 | mA | 6.80 | W | 2025-01-07 | OK
 | Oscillator | Soft Startup no C34 frequency | 190.6 | kHz |  |  | 2024-11-28 | OK | Calculated
 | Oscillator | Soft Startup no C34 lenght | 263 | ms |  |  | 2024-11-28 | OK | Calculated
x | Oscillator | Soft Startup with C34 = 22uF/1k frequency | 347 | kHz |  |  | 2024-11-28 | OK
 | Oscillator | Soft Startup with C34 = 22uF/1k lenght, f_sw 350 kHz to 94 kHz | 242 | ms |  |  | 2024-11-28 | OK
 | Oscillator | Dead time min. | 119 | ns |  |  | 2024-11-03 | OK
 | Oscillator | Dead time middle | 274 | ns |  |  | 2024-11-03 | OK
 | Oscillator | Dead time max. | 505 | ns |  |  | 2024-11-03 | OK
 | Oscillator | Dead time potentiometer dead-room | 60 | ° |  |  | 2024-11-03 | OK
 | Oscillator | Dead time, efficiency optimum 200 V | 80 | ° | 2,96 kΩ |  | 2025-01-07 | OK
 | Oscillator | Dead time, efficiency optimum 300 V | 80 | ° | 2,96 kΩ |  | 2025-01-07 | OK
 | Oscillator | Dead time, efficiency optimum 400 V | 80 | ° | 2,96 kΩ |  | 2025-01-07 | OK
 | Oscillator | Dead time, efficiency optimum 500 V | 80 | ° | 2,96 kΩ |  | 2025-01-07 | OK | optimum does not change at 100W load
 | Oscillator | Dead time, efficiency optimum 600 V | 80 | ° | 2,96 kΩ |  | 2025-01-07 | OK
 | Oscillator | frequency Potentiometer shipped | 40 | kHz |  |  | 2024-11-03 | OK
 | Oscillator | frequency min. | 20 | kHz |  |  | 2024-11-03 | OK
 | Oscillator | frequency max. | 330 | kHz |  |  | 2024-11-03 | OK
x | Oscillator | frequency min. recommended | 90 | kHz |  |  | 2024-11-03 | OK | 1,97 kΩ, but unsure what f_min is right now
 | Misc | Input reverse polarity Diode Test, 0.1A | -4.48 | V |  |  | 2024-11-28 | OK
 | Misc | Input reverse polarity Diode Test, 0.5A | -5.04 | V |  |  | 2024-11-28 | OK
 | Misc | Input reverse polarity Diode Test, 1A | -5.34 | V |  |  | 2024-11-28 | OK
 | Misc | Input reverse polarity Diode Test, 2A | -5.83 | V |  |  | 2024-11-28 | OK
 | Input | Input Voltage Ripple, 0A Load, 400V | 0.741 | Vrms |  |  | 2024-12-20 | OK | NO LISN, Direct PFC feed with SDM inbetween
 | Input | Input Voltage Ripple, 0A Load, 400V | 7.1 | Vpp |  |  | 2024-12-20 | OK but improveable | NO LISN, Direct PFC feed with SDM inbetween
 | Input | Input Voltage Ripple, 10A Load, 400V | 0.96 | Vrms |  |  | 2024-12-20 | OK | NO LISN, Direct PFC feed with SDM inbetween
 | Input | Input Voltage Ripple, 10A Load, 400V | 8.51 | Vpp |  |  | 2024-12-20 | OK but improveable | NO LISN, Direct PFC feed with SDM inbetween
 | Input | Input Voltage Ripple, 20A Load, 400V | 0.52 | Vrms |  |  | 2024-12-20 | OK | NO LISN, Direct PFC feed with SDM inbetween
 | Input | Input Voltage Ripple, 20A Load, 400V | 7.86 | Vpp |  |  | 2024-12-20 | OK but improveable | NO LISN, Direct PFC feed with SDM inbetween
 | Input | Input Voltage Ripple, 30A Load, 400V | 0.73 | Vrms |  |  | 2024-12-20 | OK | NO LISN, Direct PFC feed with SDM inbetween
 | Input | Input Voltage Ripple, 30A Load, 400V | 6.97 | Vpp |  |  | 2024-12-20 | OK but improveable | NO LISN, Direct PFC feed with SDM inbetween
 | Input | Input Voltage Ripple, 0A Load, 500V | 5.56 | Vpp |  |  | 2024-12-20 | OK but improveable | NO LISN, Direct PFC feed with SDM inbetween
 | Input | Input Voltage Ripple, 0A Load, 600V | 3.0 | Vpp |  |  | 2024-12-20 | OK but improveable | NO LISN, Direct PFC feed with SDM inbetween
 | Output | output Voltage Ripple, 0A Load, 400V | 5.1 | mVrms |  |  | 2024-12-08 | OK | T747, NO LISN, Direct Load feed
 | Output | output Voltage Ripple, 0A Load, 400V | 152 | mVpp |  |  | 2024-12-08 | OK | T747, NO LISN, Direct Load feed
 | Output | output Voltage Ripple, 10A Load, 400V | 9.1 | mVrms |  |  | 2024-12-08 | OK | T748, NO LISN, Direct Load feed
 | Output | output Voltage Ripple, 10A Load, 400V | 189 | mVpp |  |  | 2024-12-08 | OK | T748, NO LISN, Direct Load feed
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

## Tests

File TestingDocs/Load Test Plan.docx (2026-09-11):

Load Test Plan

Key Load Testing Methods and Processes

- Short-Circuit Test (https://www.google.com/search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) (Load Loss & Impedance): The secondary winding is short-circuited, and a reduced voltage is applied to the primary side until rated current flows, allowing for the measurement of copper losses and impedance.

Key Aspects of the Short-Circuit Test:

- Setup: The low-voltage (LV) side is typically short-circuited with a heavy conductor, while measuring instruments (ammeter, voltmeter, wattmeter) are connected to the high-voltage (HV) side.
- Procedure: A low-voltage supply is applied to the HV side and gradually increased until the ammeter indicates the rated full-load current flows

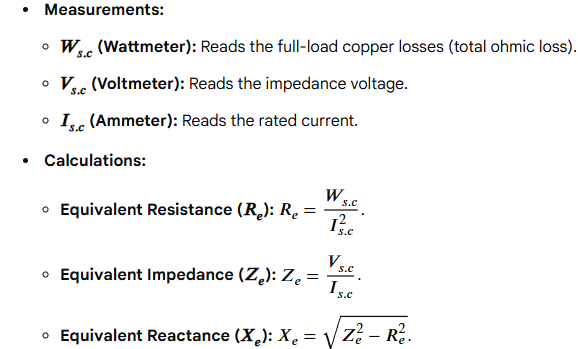
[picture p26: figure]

- Purpose: This test is essential for determining transformer voltage regulation and efficiency.

EEPower +3

Important Notes:

- Because the applied voltage is very low, the magnetic flux in the core is low, meaning iron losses are neglected.
- It is a non-destructive, economical method for calculating efficiency.
- It is generally performed on the HV side for safer, more precise, and more measurable instrument readings.

_________________________________________________________________________

- Heat Run Test (https://www.google.com/search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) (Temperature Rise): Measures the maximum temperature rise under continuous full-load conditions to ensure the cooling system operates correctly.

Key Aspects of the Heat Run Test:

- Purpose: To verify that the cooling system operates correctly and that the transformer's insulation will not be damaged by overheating.
- Methodology: The transformer is typically tested by applying rated frequency to the primary, with the secondary short-circuited to circulate the rated current.
- Measurements: The test measures the top liquid temperature rise and the average winding temperature rise.
- Duration: The test continues until the temperature stabilizes (i.e., when the temperature rise remains constant over a period).
- Compliance: Results are validated against design specifications and international standards to ensure reliability and performance.

_________________________________________________________________________

- Actual Load Test (https://www.google.com/search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): The transformer is connected to a load bank (or actual load) at its rated voltage and frequency for 1–2 hours to verify performance parameters like efficiency.

Key Objectives

- Load Loss (Copper Loss) Measurement (https://www.google.com/search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): Determines losses caused by current in the windings under actual operating conditions.
- Efficiency Evaluation (https://www.google.com/search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): Calculates efficiency by measuring power input vs. power output.
- Voltage Regulation (https://www.google.com/search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): Analyzes the change in secondary voltage from no-load to full-load, which is critical for voltage stability.
- Temperature Rise (https://www.google.com/search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): Assesses the insulation integrity under sustained operational heat.

Kingrun tester +2

Test Procedure (https://www.google.com/search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)

1. Preparation: Connect a suitable load bank (resistive or inductive) to the secondary terminals. Ensure all metering instruments (voltmeters, ammeters, wattmeters) are connected to both primary and secondary sides.
2. Energize: Apply rated voltage to the primary winding.
3. Apply Load: Gradually increase the load on the secondary side until it reaches the rated full-load current.
4. Measurements: Record primary voltage, current, and power, as well as secondary voltage and current.
5. Data Analysis: Calculate the copper losses, efficiency, and regulation using the recorded data.

Kingrun tester +4

Key Considerations

- Safety (https://www.google.com/search?q=Safety&oq=load+testing+process+for+the+transformer&sourceid=chrome&csui=3): As this involves full power, it requires appropriate precautions to avoid overheating or damage.
- Duration (https://www.google.com/search?q=Duration&oq=load+testing+process+for+the+transformer&sourceid=chrome&csui=3): Often, a heat run test (a type of load test) is conducted for several hours to ensure the temperature rise is within limits.
- Alternative Method (https://www.google.com/search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): For large transformers, a "short-circuit test (https://www.google.com/search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)" is used to simulate full-load conditions without requiring a full load bank.

_________________________________________________________________________

- Voltage Regulation Test (https://www.google.com/search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): Measures the change in secondary voltage from no-load to full-load to ensure stability.

Key Details for Testing:

- Definition: Measures the percentage change in output voltage when load changes from zero to rated capacity.
- Formula:
- Test Method: Usually determined via the Short-Circuit Test, where the secondary is shorted, and voltage is applied to the primary until full-load current flows, allowing calculation of equivalent impedance, resistance, and reactance.
- Result Interpretation: Lower regulation percentages indicate better performance (more stable voltage).
- Leading Power Factor: Zero or negative voltage regulation can occur with capacitive loads (leading PF), where the output voltage at full load is higher than at no load.
- Significance: Ensures connected electrical equipment does not receive fluctuating or excessive voltage.

_________________________________________________________________________

Key Parameters Monitored

- Copper Losses: Resistance-based losses at rated current.
- Temperature Rise: Oil and winding temperatures.
- Voltage Regulation: Stability of output voltage.
- Efficiency: Overall operational efficiency.

Standards and Tolerances

- Standards: Tests often comply with IEEE C57.12.00.
- Tolerances: Typically

for two-winding transformers and for auto-transformers.

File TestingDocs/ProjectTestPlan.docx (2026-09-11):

# Project Test Plan Group number: sdmay26-45 Project title: 600-12 Volt Converter Client &/Advisor: Formula SAE, Professor Cheng Huang

Resources:

- Build Guide
- DC-DC Table

# Transformer

## Isolation Test:

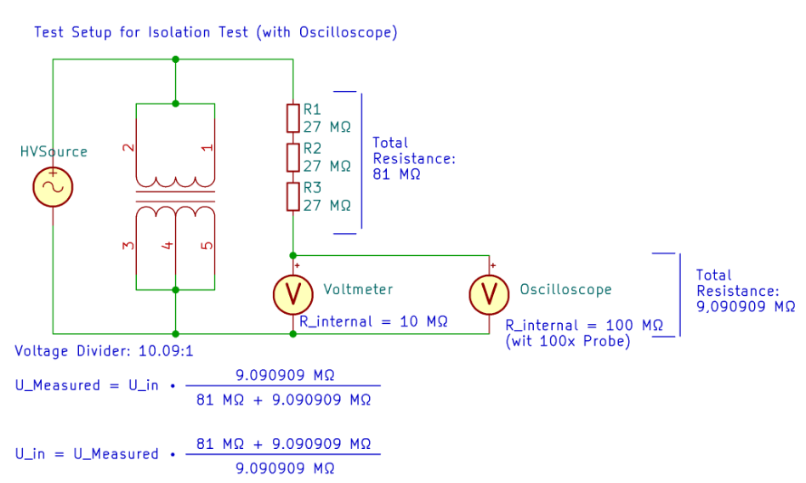
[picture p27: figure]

Figure 1: Isolation test setup (pg. 51)

Steps

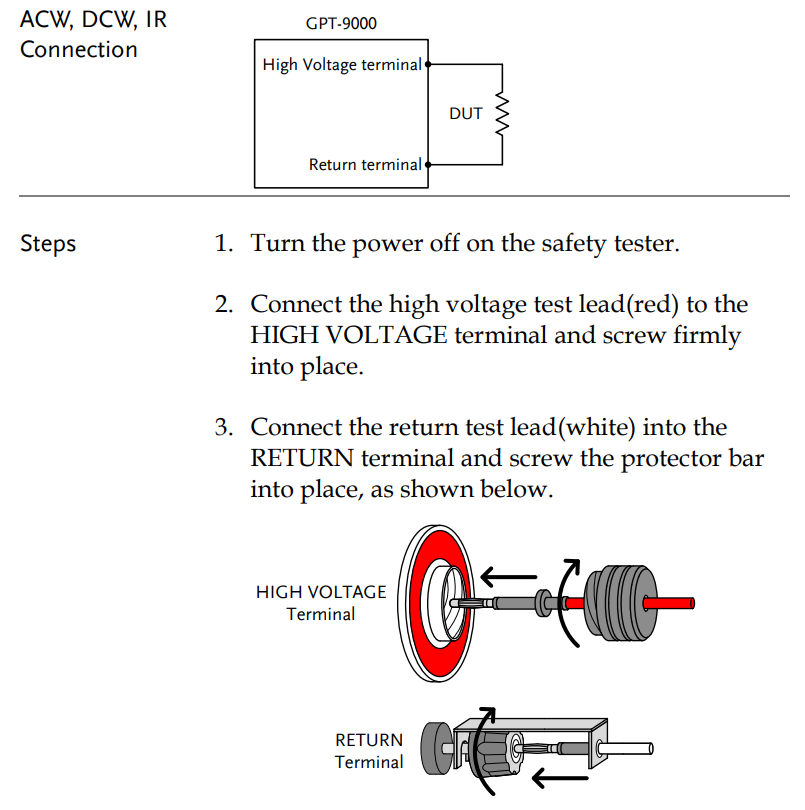
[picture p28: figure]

Figure 2: Connection to GPT-9803

1. The Isolation tester (Instek GPT-9803 Hi-Pot Tester) positive must connect to the primary side of the transformer (figure 2)
2. The secondary side of the transformer must connect to the ground of the GPT-9803 (figure 2)
3. Set voltage to 1800VAC & frequency to 60Hz
4. Run the test

## Assembly

- Verify transformer is fully de-energized and isolated from all external circuits.
- Connect transformer terminals according to the pair being tested:
  - High-Voltage Lead (HOT): primary winding terminals tied together (H1/H2).
  - Return/LOW Lead: secondary winding terminals tied together (X1/X2), or transformer core/tank depending on test.
- Ensure unused terminals are left floating unless the tester manual requires grounding.
- Attach tester’s safety ground to test bench earth.
- Confirm all personnel are clear of the test area before energizing.

## Expected Values

- Applied Voltage: 1800 VAC @ 50 Hz.
- Duration: 60 seconds.
- Leakage Current Limit: 0.5mA
- Expected Behavior:
  - No breakdown, arcing, or audible corona during test.
  - Tester completes the test without triggering “FAIL,” “ARC,” or “HV OFF” fault modes.

## Test Procedure

1. Setup and Safety
  a. Verify terminals are clean and dry
  b. Turn on & confirm GPT-9803 output is off
2. Tester Configuration
  a. Select AC Withstand Mode.
  b. Set Output Voltage to 1800 VAC.
  c. Set Frequency to 50 Hz.
  d. Set Ramp Time to default
  e. Set Test Time to 60 seconds.
  f. Set Leakage Current Trip Level: 0.5mA
  g. Enable Arc Detection
3. Isolation Test
  a. Test A: Primary to Secondary
    i. Hot lead to primary terminal.
    ii. Return lead to secondary terminal.
    iii. Start the test.
  b. Test B: Primary to Core
    i. Hot lead to primary terminal.
    ii. Return lead to core.
    iii. Start the test.
  c. Test C: Secondary to Core
    i. Hot lead to secondary terminal.
    ii. Return lead to core.
    iii. Start the test.
4. Interpreting Results
  a. Test Pass:
    i. Tester completes the full duration.
    ii. No visible discharge, change in smell, audible crackle, or insulation failure.
  b. Test Failure:
    i. GPT-9803 triggers leakage overcurrent, arc detection, breakdown, or shutdown.
    ii. Any visible arc, smoke, or audible corona.
5. Post-Test
  a. Turn HV output of GPT-9803 off.
  b. Wait for GPT-9803 & Transformer windings to discharge

## Load test:

Materials required

- High Voltage DC Source
- High Voltage Inverter
- Immersion heater
- 120VAC wall socket
- 5gal bucket of cold water
- Current clamp
- Multimeter
- Transformer
- 4/0AWG wires
- Alligator clips or lugs

Steps

1. Connect Transformer to wall socket through use of alligator clamps
2. Plug in immersion heater to wall socket (set heater to off)
3. Set up multi-meter to measure AC from the low-side of transformer
4. Connect Transformer to single pole of Inverter through use of alligator clamps and 4/0awg wire, cap or electrically isolate remaining poles
5. Connect inverter to High Voltage DC source
6. Turn on High Voltage DC source after making sure the inverter is pre-charged
7. Measure AC voltage from low-side of transformer, if below 20VAC proceed to next step
8. Using a current clamp connected to the multi-meter, clamp around the immersion heater wires
9. Measure current & Voltage at the same time, assume power loss is negligible
10. Control power going into transformer through use of the inverter.

# Printed Circuit Board:

## Test: Initial Test Without HV Input

### Required Materials:

- Testing Tools
  - DC Power Supply (Coover)
  - Voltmeter (Coover)
- DC/DC Parts
  - Lithium Capacitor

Process:

1. Keep DC power supply output OFF for this step. Set DC power supply to a current of 100 mA and 0V. Connect it to the output of the DC/DC with the same polarity.
2. Slowly turn the DC power supply output to ON. Turn the voltage of DC power supply to 12 V.
  a. Check for voltage of 3.6 to 3.8 V between pads of C_(start1)
  b. Check that the 5 V LED lights up
3. Enable switch on DCDC
  a. Check for a voltage of 12 to 12.5 V between pads 1 and 2 of U1
  b. Check that 12 V and power LEDs light up
  c. Check that input current at 23V is 20 - 30 mA.
4. Insert the super cap ( C_(start1) ).
  a. Be careful in this step! The capacitor is charged between 3.6 to 3.8 V.
  b. Be careful not to short the circuit in this step
5. Remove R61 to deactivate UVP/OVP

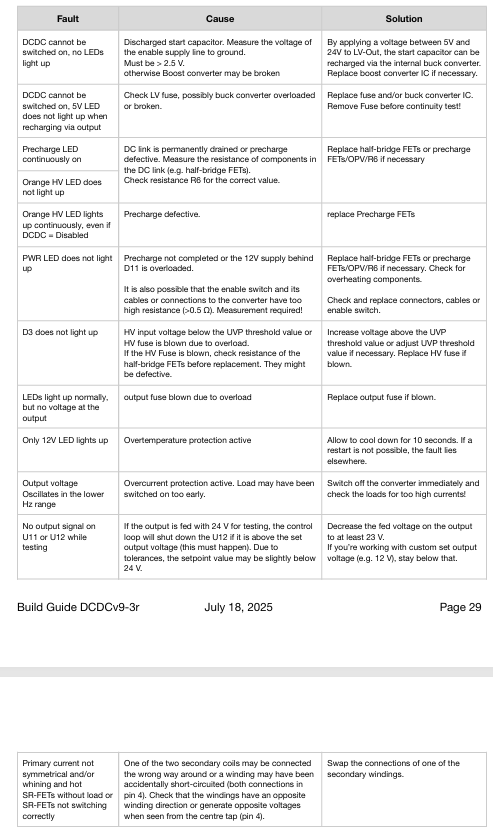
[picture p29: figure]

Test:

1. Check for square waves, measured against ground: U12 pins 5 and 8, Q10 and Q11 pin 1 (gate).
2. Apply low voltage, like 10V or 100mA to HV input.

Required Materials:

Process:

## Initial test without HV input:

-Set constant current of 100mA and 0V on the Lab power supply with output Off connected to the output of the DCDC with the same polarity.

-Slowly increase the voltage on the laboratory power supply to max. 23V. A voltage of between 3.6 and 3.8 V should be at the pads of C_(start) 1 and the 5V LED should light up. -Switch on the DCDC with an enable switch. Approx. 12 to 12.5 Volt should be present between pads 1 and 2 of U1 and the 12V and Pwr LEDs should light up. The input current at 23V should be between 20 and 30 mA.

-Insert the lithium capacitor. Do not short circuit both contacts when trimming the connections.

-Remove R61 to deactivate UVP/OVP.

-Check whether square wave signals are present, measured against ground: U12 pins 5 and 8, Q10 and Q11 pin 1 (gate).

-Do not set output above 23V for testing.

-Apply a low voltage (e.g. 10V / 100mA ) to the HV input.

## Test Set up:

At the HV input:

- Voltage source 0 – 600 V / 0-2 A
- Multimeters for voltage and current measurement
  - The multimeters are connected voltage-based, i.e. voltage measurement behind the current meter, followed by the DCDC

On the LV output:

- Power sink 24V / max. 0 –31.25 A
- Multimeter for voltage measurement (connected via measuring points J4)
- Multimeter for current measurement (or measurement of the current via a suitable shunt)
- Laboratory power supply unit for charging the start capacitor (suitable for 5-24 V)

On the DCDC with oscilloscope:

- A) Voltage measurement via Cres (HV! Only suitable if differential HV probes up to 600V are available or oscilloscope has isolated measurement inputs)
- B) Current measurement (insulated current measuring coil) via a transformer cable. The measured values of both measurement methods (A/B) can be approximately converted into each other, so it is not necessary to measure both. However, the current measurement may be more suitable for understanding the actual load on the transformer.
- Voltage measurement via drain source and gate source on one of the SR MOSFETS (Q8 or Q9)
- Measurements via C1 (HV!) to check the precharge
- HV input and LV output for ripple voltage measurements

Other measurements:

- Room temperature (for isolation measurement also humidity)
- Thermal imaging camera (highly recommended!), alternatively, IR thermometer (way less accurate, does not measure to a precise point, reflections not recognizable.

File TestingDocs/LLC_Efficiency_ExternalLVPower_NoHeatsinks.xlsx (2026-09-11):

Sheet: 115 kHz
Efficiency (%) | Output Load (CC) (A) | Input Current (A)
55.40166205 | 1 | 0.038 | Input Voltage | 580
70.1754386 | 2 | 0.06 | Output Voltage | 12
77.97270955 | 3 | 0.081
82.55933953 | 4 | 0.102
85.57980317 | 5 | 0.123
87.71929825 | 6 | 0.144
89.31419458 | 7 | 0.165
90.54895303 | 8 | 0.186
91.09311741 | 9 | 0.208
91.93288899 | 10 | 0.229
92.26252883 | 11 | 0.251
92.87925697 | 12 | 0.272
93.08986753 | 13 | 0.294
93.56725146 | 14 | 0.315
93.70607528 | 15 | 0.337
94.08997354 | 16 | 0.358
94.18282548 | 17 | 0.38
94.50059063 | 18 | 0.401
94.56264775 | 19 | 0.423
94.61856889 | 20 | 0.445
94.66922123 | 21 | 0.467
94.7153159 | 22 | 0.489
94.94324045 | 23 | 0.51
94.9742778 | 24 | 0.532
95.00285009 | 25 | 0.554
95.02923977 | 26 | 0.576
94.89500044 | 27 | 0.599
94.92329858 | 28 | 0.621
94.94966031 | 29 | 0.643
94.9742778 | 30 | 0.665
94.99731862 | 31 | 0.687
94.88510007 | 32 | 0.71
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

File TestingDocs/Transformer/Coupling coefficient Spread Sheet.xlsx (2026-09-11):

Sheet: Rev.8 (28-1)
 |  |  |  | Coupling Coefficient (k) Secondary short circuited |  | Coupling Coefficient (k) Primary short circuited
 |  |  |  | L,p,open (µH) | 161.1704 | L,s,open (µH)
 |  |  |  | L,sec,sc (µH) | 58.40398 | L,pri,sc (µH)
 |  |  |  | k (0-1) | 0.799 | k (0-1) | #DIV/0!
Measured on KeySight E4980AL Percision LCR Meter (1V 100kHz)
Modul | Parameter | Typ. | Unit
Inductance W1 |  | 161.1704 | µH
Stray Inductance W1 | W2 Short Circuit | 58.40398 | µH
 | W3 Short Circuit | 58.56323 | µH
Inductance | W2 open |  | µH
 | W3 open |  | µH
Stray Inductance | W2 open, W1 short circuit |  | µH
 | W3 open, W1 short circuit |  | µH

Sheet: Rev.7 (28-1)
 |  |  |  | Coupling Coefficient (k) Secondary short circuited |  | Coupling Coefficient (k) Primary short circuited
 |  |  |  | L,p,open (µH) | 163 | L,s,open (µH)
 |  |  |  | L,sec,sc (µH) | 76 | L,pri,sc (µH)
 |  |  |  | k (0-1) | 0.731 | k (0-1) | #DIV/0!
Measured on KeySight E4980AL Percision LCR Meter (1V 100kHz)
Modul | Parameter | Typ. | Unit
Inductance W1 |  | 163 | µH
Stray Inductance W1 | W2 Short Circuit | 76 | µH
 | W3 Short Circuit | 80 | µH
Inductance | W2 open |  | µH
 | W3 open |  | µH
Stray Inductance | W2 open, W1 short circuit |  | µH
 | W3 open, W1 short circuit |  | µH

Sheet: Rev.6 (28-1)
 |  |  |  | Coupling Coefficient (k) Secondary short circuited |  | Coupling Coefficient (k) Primary short circuited
 |  |  |  | L,p,open (µH) | 147 | L,s,open (µH)
 |  |  |  | L,sec,sc (µH) | 104 | L,pri,sc (µH)
 |  |  |  | k (0-1) | 0.541 | k (0-1) | #DIV/0!
Measured on KeySight E4980AL Percision LCR Meter (1V 100kHz)
Modul | Parameter | Typ. | Unit
Inductance W1 |  | 147.854 | µH
Stray Inductance W1 | W2 Short Circuit | 104 | µH
 | W3 Short Circuit |  | µH
Inductance | W2 open |  | µH
 | W3 open |  | µH
Stray Inductance | W2 open, W1 short circuit |  | µH
 | W3 open, W1 short circuit |  | µH

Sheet: Rev.5 (possible 28-2)
 |  |  |  | Coupling Coefficient (k) Secondary short circuited |  | Coupling Coefficient (k) Primary short circuited
 |  |  |  | L,p,open (µH) | 163.076 | L,s,open (µH)
 |  |  |  | L,sec,sc (µH) | 54.557 | L,pri,sc (µH)
 |  |  |  | k (0-1) | 0.816 | k (0-1) | #DIV/0!
Measured on KeySight E4980AL Percision LCR Meter (1V 100kHz)
Modul | Parameter | Typ. | Unit
Inductance W1 |  | 162.737 | µH
Stray Inductance W1 | W2 Short Circuit | 54.053 | µH
 | W3 Short Circuit | 53.053 | µH
Inductance | W2 open | 1.109 | µH
 | W3 open | 1.059 | µH
Stray Inductance | W2 open, W1 short circuit | 0.124 | µH
 | W3 open, W1 short circuit | 0.122 | µH

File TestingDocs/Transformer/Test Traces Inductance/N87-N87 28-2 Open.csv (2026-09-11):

#Digilent WaveForms Impedance Analyzer Trace#Trace: Ref 1
#Start: 2000 Hz
#Stop: 5e+06 Hz
#Steps: 201
#Order: W1-C1-DUT-C2-R-GND
#Resistor: 10 O
#Average: 1
#ProbeResistance: 1.04e+06 O
#ProbeCapacitance: 4.3e-11 F
#Compensation:none
#Amplitude: 4 V
#Offset: 0 V
#Amplification: 1 X
#Settle: 0.01 s
#MinPeriods: 16
#Scale: Logarithmic
Frequency (Hz) | Gain (X) | Phase (rad) | Real (Ohm) | Imag (Ohm) | VReal (V) | VImag (V) | IReal (A) | IImag (A) | Resistor (Ohm) | Amplitude (V) | Offset (V)
2000.000000000003 | -0.7881876699685366 | -2.935440335111764 | -12.07315990431494 | -0.4335002973695438 | -0.01156823525728248 | -0.0004154330031110882 | -0.0009575608525179249 | -3.438747326414453e-05 | 10 | 4 | 0
2079.791005654459 | -0.8251026201080061 | -3.133033582402399 | -11.74879685095504 | -0.01490324732138345 | -0.01176813158421417 | -1.499389923437543e-05 | -0.001001644871849791 | -1.276206181896422e-06 | 10 | 4 | 0
2162.765313600588 | -0.7943457996159206 | -2.924157555138634 | -12.00800574709104 | -0.4435747933192047 | -0.01222818471103346 | -0.0004517797367345046 | -0.001017641935251955 | -3.759756795162645e-05 | 10 | 4 | 0
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

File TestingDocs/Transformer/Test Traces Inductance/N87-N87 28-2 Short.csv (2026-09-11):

#Digilent WaveForms Impedance Analyzer Trace#Trace: Trace
#Start: 2000 Hz
#Stop: 5e+06 Hz
#Steps: 201
#Order: W1-C1-DUT-C2-R-GND
#Resistor: 10 O
#Average: 1
#ProbeResistance: 1.04e+06 O
#ProbeCapacitance: 4.3e-11 F
#Compensation:none
#Wavegen: Wavegen1
#Amplitude: 4 V
#Offset: 0 V
#Amplification: 1 X
#Settle: 0.01 s
#MinPeriods: 16
#Scale: Logarithmic
Frequency (Hz) | Gain (X) | Phase (rad) | Real (Ohm) | Imag (Ohm) | VReal (V) | VImag (V) | IReal (A) | IImag (A) | Resistor (Ohm) | Amplitude (V) | Offset (V)
2000.000000000003 | -0.8040486326652362 | -3.106761295162695 | -11.95821051505575 | -0.06817345083330176 | -0.01257834691408535 | -7.177680165759343e-05 | -0.001051841535816937 | -6.002205361899158e-06 | 10 | 4 | 0
2079.791005654459 | -0.8083691334305708 | -3.081414154562336 | -11.91272590484785 | -0.1151829406046858 | -0.01330147329830462 | -0.0001286853473387064 | -0.00111652460456981 | -1.080183776105396e-05 | 10 | 4 | 0
2162.765313600588 | -0.8357556015131438 | -3.067197251214664 | -11.63778969437293 | -0.1220084222048943 | -0.01327923000808853 | -0.0001392945793293417 | -0.001140981290630145 | -1.196850335480053e-05 | 10 | 4 | 0
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

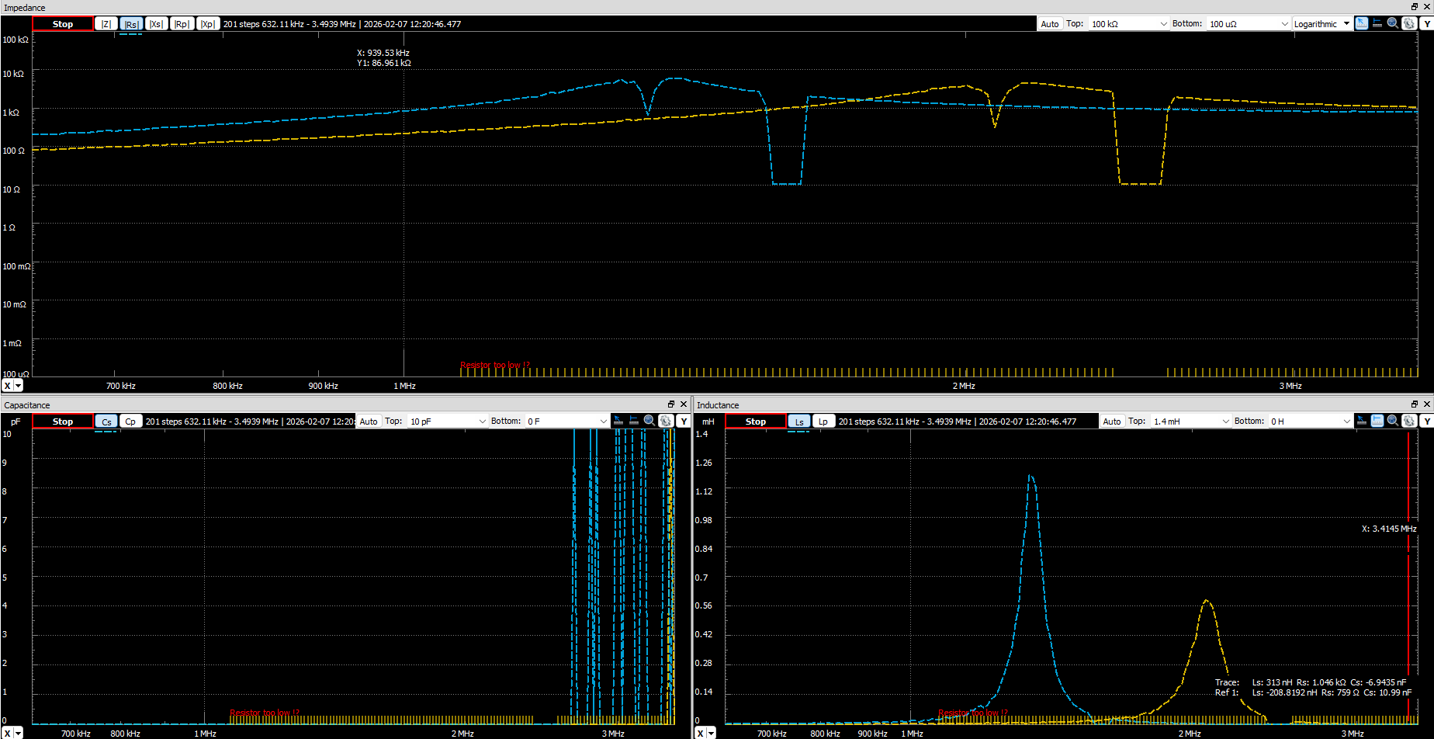
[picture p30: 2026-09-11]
TestingDocs/Transformer/Test Traces Inductance/N97-N27 28-2.png

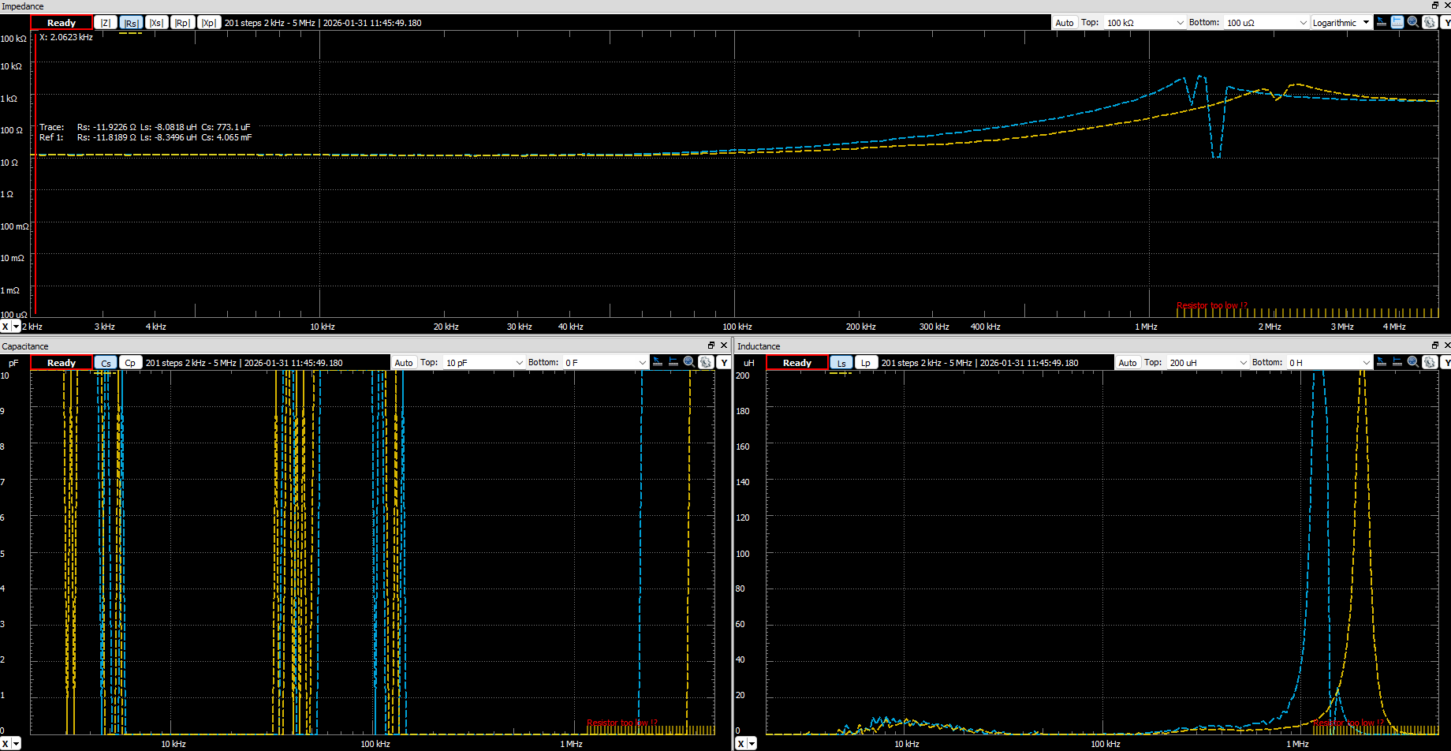
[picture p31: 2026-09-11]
TestingDocs/Transformer/Test Traces Inductance/M87-N87 28-2 test.png

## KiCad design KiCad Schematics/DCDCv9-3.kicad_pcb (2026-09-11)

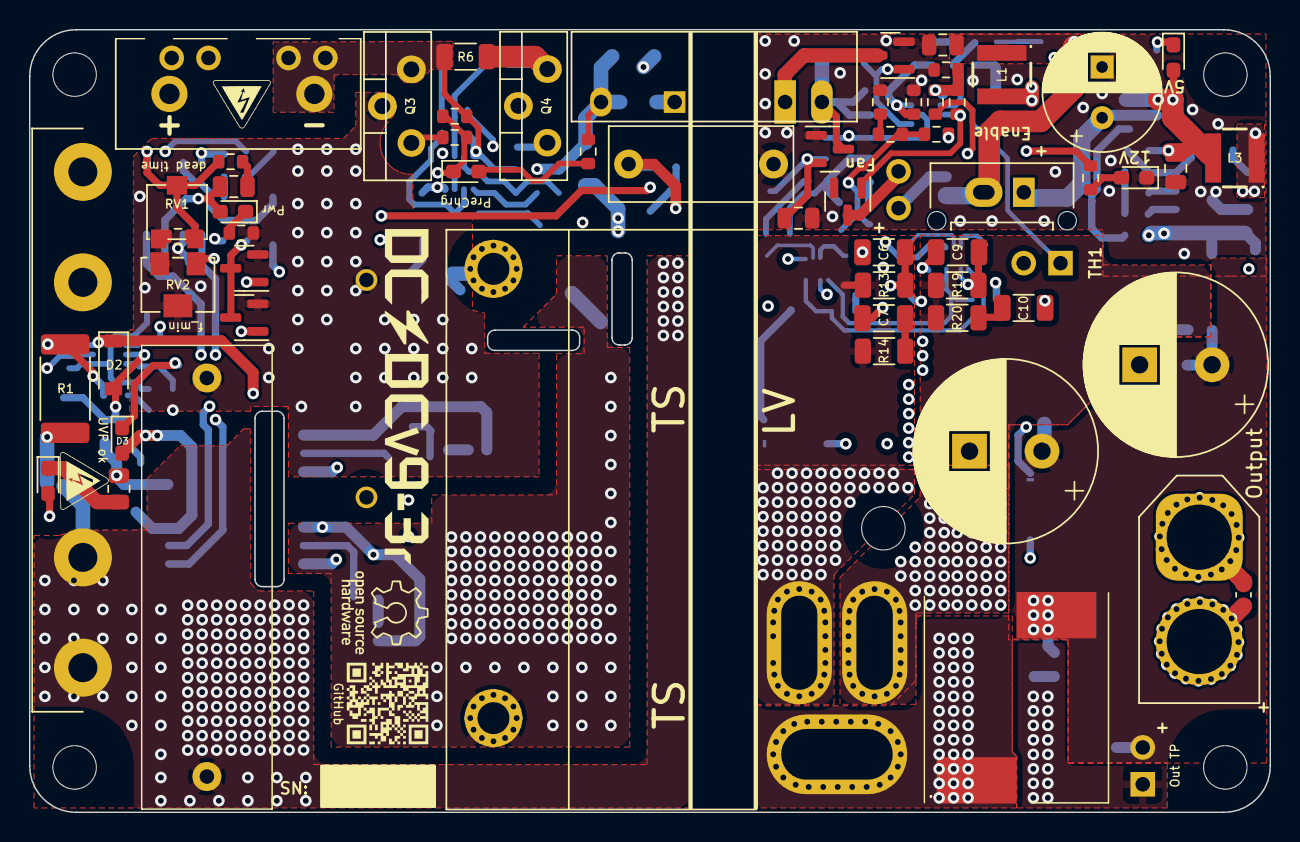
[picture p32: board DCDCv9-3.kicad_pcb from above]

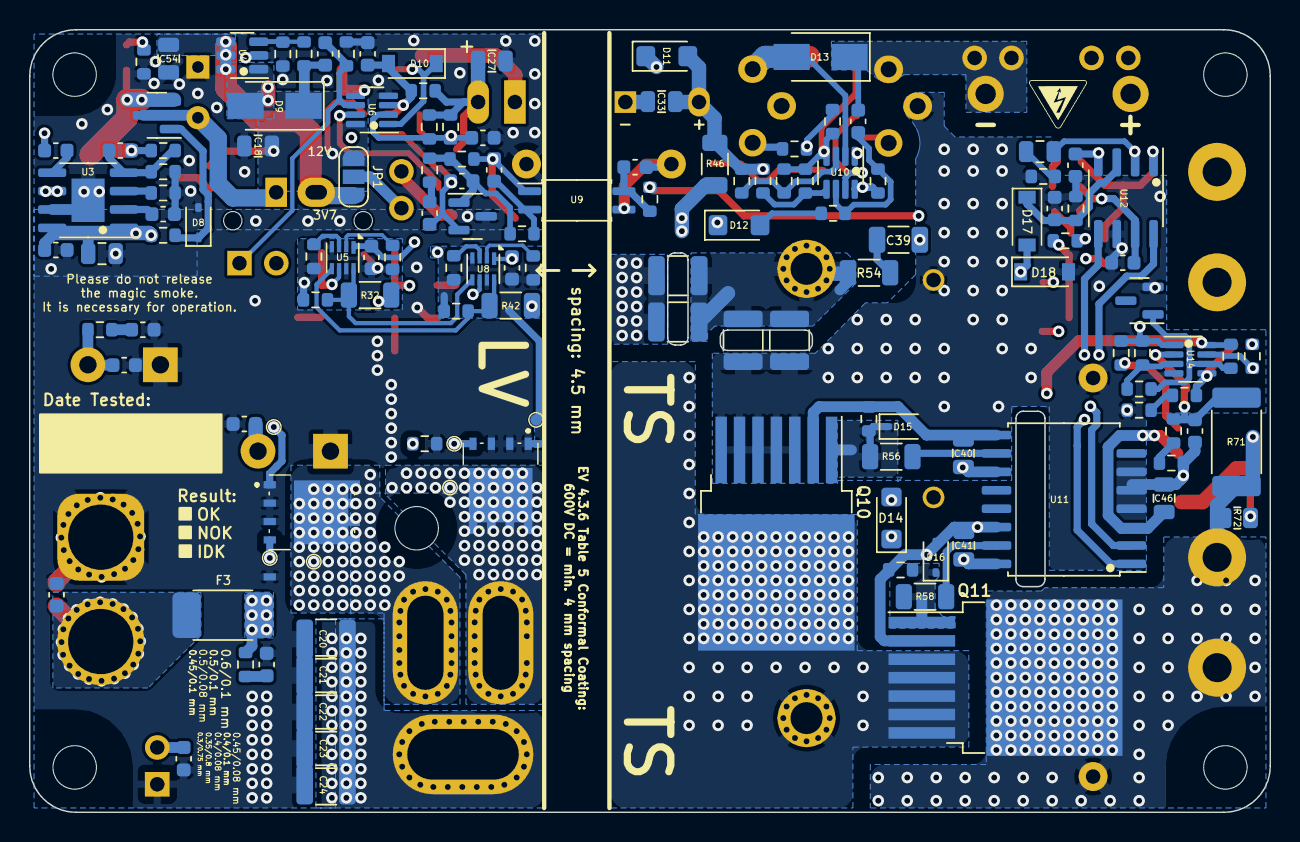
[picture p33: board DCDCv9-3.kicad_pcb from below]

Board: 4 copper layers, 85.6 x 54.0 mm, 206 parts (139 on the bottom side), 102 nets.

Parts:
C1: 2uF; MKP1848520704K2
C2, C15, C40, C41: 2.2uF; C_0805_2012Metric
C3: 22nF; R76UI22205050J
C4: 3.3nF; C_Disc_D12.5mm_W5.0mm_P10.00mm
C5, C33, C46: 10uF; C_0805_2012Metric
C6, C9: 1 nF; C_1206_3216Metric
C7, C10, C39: 470pF; C_1206_3216Metric
C8, C12, C18, C27, C42, C54: 22uF; C_0805_2012Metric
C11, C13: 2200uF; CP_Radial_D12.5mm_P5.00mm_symbol_inside
C14, C28: 100nF; C_0603_1608Metric
C16, C49, C50, C51, C52, C53, C55, C56, C57: 1nF; C_0603_1608Metric
C17, C19, C25, C31, C45: 1uF; C_0603_1608Metric
C20, C21, C22, C23, C24: 10uF; C_1210_3225Metric
C26, C44, C47: 22nF; C_0603_1608Metric
C29: 47pF; C_0603_1608Metric
C30, C32, C48: 10nF; C_0603_1608Metric
C34, C35, C36, C37: 5.6nF; C_1210_3225Metric
C38: 120pF; C_0603_1608Metric
C43: 470nF; C_0603_1608Metric
C_start1: 3.8V 25F Supercap; CP_Radial_D8.0mm_P3.50mm
D1: HV_Orange; LED_0603_1608Metric_Pad1.05x0.95mm_HandSolder
D2, D10, D17, D18: 1N4448; D_SOD-123
D3, D4, D5, D6, D7: Green; LED_0603_1608Metric_Pad1.05x0.95mm_HandSolder
D8, D15, D16: CDSOD323-T12; D_SOD-323
D9, D13: SS1H10; D_SMA
D11, D12, D14: VS-E7FX0212-M3/I; D_SMF
F1: 1.6A; Fuseholder0,25Zoll_32mm_littlefuse_102_122
F3: 20A; Bel_SMCF_Fuse_2410_6125Metric
HV_Logo_1, HV_Logo_1#2, HV_Logo_1#3: HV_Logo_1; HV_Logo_small
J1: Screw_Terminal_01x03; TerminalBlock_TE-282817-2_1x03_P5.00mm_90 Degrees updated v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
J2, J4, J6, J7, J8: Conn_01x02_Male; PinHeader_1x02_P2.54mm_Vertical
J3: Conn_01x02; Molex_Micro-Fit_3.0_43650-0215_1x02_P3.00mm_Vertical_combin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
J5: XT60 Male; AMASS_XT60-F_1x02_P7.20mm_Vertical
JP1: Fan Voltage Select; SolderJumper-3_P1.3mm_Open_RoundedPad1.0x1.5mm_NumberLabels
L1: 4.7uH; ASPI-4030S
L2: 1uH; 7443091100_v9.2
L3: 10uH; ASPI-4030S
NT1, NT2: NetTie_2; dummy_net_line_0.5mm
Q1, Q2, Q5, Q6, Q7: PMV20ENR; SOT-23
Q3: SIHP24N80AE-GE3; TO-220-3_Vertical_HV1.2mm
Q4: IXYP8N90C3; TO-220-3_Vertical_HV1.2mm
Q8, Q9: BSC027N06LS5ATMA1
Q10, Q11: IMBG65R050M2HXTMA1; TO-263-7_TabPin8
QR_Coode_1: QR_Coode; GitHub_QR_Code
R1, R71: 100M; R_2512_6332Metric_Pad1.40x3.35mm_HandSolder
R2, R72: 330k; R_0805_2012Metric
R3: 3.0k; R_0603_1608Metric
R4, R39, R41, R59, R61: 1k; R_0603_1608Metric
R5, R7, R9, R11, R15, R16, R21, R23, R30, R33, R40, R43, R51, R52, R55, R57, R63: 10k; R_0603_1608Metric
R6, R14, R20: 47; R_1206_3216Metric
R8, R10, R22, R29, R38, R48, R49: 2.2k; R_0603_1608Metric
R12: 910; R_0603_1608Metric
R13, R19: 100; R_1206_3216Metric
R17, R24: 27k; R_0603_1608Metric
R18, R27, R50: 470k; R_0603_1608Metric
R25: 240k; R_0603_1608Metric
R26, R45, R47, R53, R67, R70: 100k; R_0603_1608Metric
R28, R34, R66: 33k; R_0603_1608Metric
R31, R36: 4.7k; R_0603_1608Metric
R32, R42: 4.7; R_1206_3216Metric
R35: 330k; R_0603_1608Metric
R37: 47k; R_0603_1608Metric
R44: 510; R_0603_1608Metric
R46: 20; R_1206_3216Metric
R54: 10M; R_1206_3216Metric
R56, R58: 10; R_1206_3216Metric
R60: 82k; R_0603_1608Metric
R62, R69: 100M; R_0603_1608Metric
R64: 820k; R_0603_1608Metric
R65: 510k; R_0603_1608Metric
R68: 1.6M; R_0603_1608Metric
R73, R74: 10; R_0603_1608Metric
RV1: 20k; Potentiometer_Bourns_PVG3G
RV2: 10k; Potentiometer_Bourns_3214W_Vertical
T1: DIY Transformer ETD 39; Transformer_ETD39_uprightV3.6 (PSS 24V)
TH2: 1k PTC; R_0603_1608Metric
TP1, TP2, TP3, TP4, TP5, TP6: TestPoint; TestPoint_Pad_D0.8mm_DC-DC
TP8: GaN GND2; TestPoint_Pad_D0.8mm_DC-DC
U1: TBA 1-1212HI; Converter_DCDC_TRACO_TBA 1-1212HI-3kV-iso
U2: RT9058-90GVL; SOT-23
U3: MP4541_SOP8-EP; SOIC-8-1EP_3.9x4.9mm_P1.27mm_EP2.29x3mm XL7005
U4: TLV61048DBVR; SOT-23-6
U5, U8: NCP4305DMTTWG; WDFN-8_2x2mm_P0.5mm
U6, U10, U14: LM2904BIDDFR; SOT-23-8_DC-DC_v9
U7: TL431; SOT-23
U9: ACPL-217-50AE; SOIC-4_4.55x2.6mm_P1.27mm
U11: UCC21520DW; SOIC-16W_7.5x10.3mm_P1.27mm
U12: UCC25600; SOIC-8_3.9x4.9mm_P1.27mm
U13: ZXRE330ASA-7; SOT-23

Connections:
24V_TP: C11.1, C13.1, C50.2, C51.2, C52.2, F3.1, J4.1, L2.2, R17.1, R73.1, R74.1
+3V7: C8.1, C54.1, J3.2, JP1.3 (B), L1.1, U4.4 (~SHDN), U4.5 (IN), U4.6 (nc)
+9V: C5.1, C30.2, R39.1, U2.2 (VO), U9.1
+12V_HS: C41.2, D14.1 (K), U11.16 (VDDA)
+12V_IN: C2.2, C40.2, C45.2, C46.1, D2.1 (K), D3.2 (A), D4.2 (A), D11.1 (K), R70.1, U11.3 (VCCI), U11.8 (VCCI), U11.11 (VDDB), U12.7 (VCC), U14.8 (V+)
+12V_sw: C18.1, C19.2, C25.1, C27.1, C31.1, D9.1 (K), J8.1, JP1.1 (A), R16.1, R21.2, R27.1, R34.1, R35.2, R36.2, U1.1 (+VIN), U2.3 (VI), U5.1 (VCC), U6.8 (V+), U8.1 (VCC)
+24V: C15.2, C53.2, R26.2, U3.1 (EN), U3.8 (VIN)
+HV: C1.2, C34.1, C35.1, F1.2, Q11.8 (D), R1.1, R71.1, R72.1
+HV_in: F1.1, J1.2, J7.1, J7.2
-HV_in: C33.2, C38.1, D13.1 (K), J1.1, J6.1, J6.2, Q3.3 (S), R6.2, R7.2, R48.1, R50.1, R51.2, U1.5 (-VOUT), U10.4 (V-)
-HV_pc: C1.1, C3.2, C4.1, C32.2, C36.2, C37.2, C43.2, C44.1, C45.1, C46.2, C47.2, D12.1 (K), D18.2 (A), Q1.2 (S), Q2.2 (S), Q3.2 (D), Q4.2 (C), Q10.3 (S), Q10.4 (S), Q10.5 (S), Q10.6 (S), Q10.7 (S), R2.2, R3.2, R5.1, R59.2, R60.1, R65.2, R68.2, RV1.3, RV2.2, RV2.3, U9.3, U11.4 (GND), U11.5 (DIS), U11.6 (DT), U12.6 (GND), U13.2, U14.4 (V-)
/HB_out: Q10.8 (D), Q11.3 (S), Q11.4 (S), Q11.5 (S), Q11.6 (S), Q11.7 (S), T1.1 (AA)
/HS: U11.1 (INA), U12.8 (GD1)
/LS: U11.2 (INB), U12.5 (GD2)
/OC: C44.2, D17.1 (K), R60.2, U12.3 (OC)
/OTP_FAN: Q5.1 (G), R18.1, U6.7
/OTP_OFF: D10.1 (K), Q6.1 (G), U6.1
/OVP: Q2.1 (G), R69.1, U14.7
/Opc+: C32.1, R44.2, U9.4
/Synchronous Rectification/3: Q9.5 (D_1), Q9.6 (D_2), Q9.7 (D_3), Q9.8 (D_4), Q9.9 (D_5), R13.2, R14.1, T1.3 (SB), TP5.1
/Synchronous Rectification/5: Q8.5 (D_1), Q8.6 (D_2), Q8.7 (D_3), Q8.8 (D_4), Q8.9 (D_5), R19.2, R20.1, T1.5 (SA), TP3.1
/UVP: Q1.1 (G), R62.1, R63.1, U14.1
GND: C4.2, C5.2, C7.1, C8.2, C10.1, C11.2, C12.1, C13.2, C15.1, C17.1, C18.2, C20.2, C21.2, C22.2, C23.2, C24.2, C27.2, C28.1, C48.1, C49.1, C50.1, C51.1, C52.1, C53.1, C54.2, C55.1, C56.1, C57.1, C_start1.2 (-), D6.1 (K), D8.2 (A2), J4.2, J5.2, NT1.2, NT2.2, Q5.2 (S), Q6.2 (S), Q8.1 (S_1), Q8.2 (S_2), Q8.3 (S_3), Q9.1 (S_1), Q9.2 (S_2), Q9.3 (S_3), R10.2, R11.2, R15.1, R22.1, R23.2, R25.1, R28.2, R31.1, TH2.2, TP8.1, U2.1 (GND), U3.7 (GND), U4.2 (GND), U6.4 (V-), U7.3 (A)
unnamed: C2.1, R4.2
unnamed: C7.2, R14.2
unnamed: C10.2, R20.2
unnamed: C26.2, R37.1
unnamed: C30.1, R41.1, U9.2
unnamed: C39.2, R54.1
unnamed: C42.2, R59.1
unnamed: C56.2, R73.2
unnamed: C57.2, R74.2
unnamed: C_start1.1 (+), J3.1, Q7.3 (D)
unnamed: D1.2 (A), R72.2
unnamed: D1.1 (K), R2.1
unnamed: C47.1, D2.2 (A), R67.2, R71.2, U14.2 (-)
unnamed: D3.1 (K), R63.2
unnamed: D4.1 (K), R5.2
unnamed: D5.2 (A), R9.1
unnamed: D5.1 (K), R7.1, R8.2, U10.7
unnamed: D6.2 (A), R21.1
unnamed: C12.2, C16.2, D7.2 (A), L3.2, Q7.2 (S), R24.1
unnamed: D7.1 (K), R22.2
unnamed: D8.1 (A1), Q7.1 (G), R26.1
unnamed: D9.2 (A), L1.2, U4.1 (SW)
unnamed: C48.2, D10.2 (A), R11.1, R34.2, U6.3 (+)
unnamed: C33.1, D11.2 (A), R9.2, R45.2, R46.2, R47.2, R53.2, U1.7 (+VOUT), U10.8 (V+)
unnamed: D12.2 (A), R52.1
unnamed: D13.2 (A), Q4.3 (E), R6.1, U10.2 (-)
unnamed: D14.2 (A), R46.1
unnamed: D15.1 (A1), Q10.1 (G), R55.1, R56.1
unnamed: C40.1, D15.2 (A2), Q10.2 (DS), R55.2, U11.9 (VSSB)
unnamed: D16.1 (A1), Q11.1 (G), R57.1, R58.1
unnamed: C41.1, D16.2 (A2), Q11.2 (DS), R57.2, U11.14 (VSSA)
unnamed: C39.1, D17.2 (A), D18.1 (K)
unnamed: J2.1, JP1.2 (C)
unnamed: J2.2, Q5.3 (D)
unnamed: C49.2, C55.2, F3.2, J5.1
unnamed: C19.1, J8.2, R31.2, U6.6 (-)
unnamed: Q1.3 (D), Q2.3 (D), R61.1
unnamed: Q3.1 (G), R8.1
unnamed: Q4.1 (G), R49.1
unnamed: Q8.4 (G), R32.1, TP2.1
unnamed: Q9.4 (G), R42.1, TP4.1
unnamed: R10.1, R12.2
unnamed: R49.2, R51.1, U10.1
unnamed: R65.1, R66.2
unnamed: R67.1, R68.1
unnamed: C34.2, C35.2, C36.1, C37.1, R54.2, T1.2 (AB)
unnamed: C20.1, C21.1, C22.1, C23.1, C24.1, L2.1, T1.4 (SC)
unnamed: C14.2, U3.5 (BST)
unnamed: C16.1, R23.1, R24.2, U3.4 (FB)
unnamed: R25.2, U3.3 (FREQU)
unnamed: C14.1, L3.1, U3.6 (SW)
unnamed: C17.2, U3.2 (VCC)
unnamed: R27.2, R28.1, U4.3 (FB)
unnamed: C9.2, R19.1, U5.6 (CS)
unnamed: R30.2, R32.2, U5.8 (DRV), U8.5 (TRIG/DIS)
unnamed: C9.1, C25.2, NT1.1, R29.1, R30.1, R33.1, TP1.1, U5.4 (LLD), U5.7 (GND)
unnamed: R33.2, U5.2 (MIN_TOFF)
unnamed: R29.2, U5.3 (MIN_TON)
unnamed: R40.2, R42.2, U5.5 (TRIG/DIS), U8.8 (DRV)
unnamed: C28.2, R35.1, R36.1, TH2.1, U6.2 (-)
unnamed: R15.2, R16.2, R18.2, U6.5 (+)
unnamed: C29.2, R37.2, R39.2, R41.2, U7.1 (K)
unnamed: C26.1, C29.1, R12.1, R17.2, U7.2 (REF)
unnamed: C6.2, R13.1, U8.6 (CS)
unnamed: C6.1, C31.2, NT2.1, R38.1, R40.1, R43.1, TP6.1, U8.4 (LLD), U8.7 (GND)
unnamed: R43.2, U8.2 (MIN_TOFF)
unnamed: R38.2, U8.3 (MIN_TON)
unnamed: R45.1, R48.2, U10.3 (+)
unnamed: R47.1, R50.2, U10.5 (+)
unnamed: C38.2, R52.2, R53.1, U10.6 (-)
unnamed: R58.2, U11.15 (OUTA)
unnamed: R56.2, U11.10 (OUTB)
unnamed: R3.1, R4.1, RV1.1, RV1.2, U12.1 (DT)
unnamed: C42.1, R44.1, RV2.1, U12.2 (RT)
unnamed: C43.1, R61.2, U12.4 (SS)
unnamed: R62.2, R64.1, U14.3 (+)
unnamed: R1.2, R66.1, R69.2, U14.5 (+)
unnamed: R64.2, R70.2, U13.1, U14.6 (-)
OTP_FET: Q6.3 (D), U1.2 (-VIN)
